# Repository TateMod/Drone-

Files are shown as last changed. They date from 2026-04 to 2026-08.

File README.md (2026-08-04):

drone pcb and c++ develpmnet in progress (MK2) see branch for updates

An open-source sub-250g quadcopter UAV built on custom MicroPython firmware developed from first principles. The platform provides full access to flight control algorithms including PID attitude control, complementary filter sensor fusion, motor mixing, optical flow position hold and TOF altitude hold. Designed to be reproducible and accessible for learning and further development.
this project originated as a dissertation project and where i gave weekly updates to my unis robotics club explaining my work

NOTE: testing with higher I term on all axis test rig to counteract persistence drift and imbalances
---

## pictures




## Demo Videos

| Description | Link |
|---|---|
| Direction control verification | [Watch](https://youtube.com/shorts/0nLSP_-wE7E) |
| Flight with large drop | [Watch](https://youtube.com/shorts/2Yogxh4Vv3w) |
| 1 min tethered flight | [Watch](https://youtube.com/shorts/OXTsZ9uvmPU) |
| Rig test | [Watch](https://youtube.com/shorts/fh2ME875rF4) |
| PID test | [Watch](https://youtube.com/shorts/FNgBR3Ud5JU) |
| Wobbly PID test | [Watch](https://youtube.com/shorts/QxyQJRjCvH8) |

---

## Repository Structure

```
/firmware          - Pico W2 flight controller MicroPython source code
/companion         - Raspberry Pi Zero W2 telemetry and camera code
/schematics        - Wiring diagrams and circuit schematics (EasyEDA)
/frame             - 3D printable CAD frame files (STL and OnShape)
/docs              - Build guide and assembly documentation
```

---

## Components

### Computing
| Component | Purpose |
|---|---|
| Raspberry Pi Pico W2 | Flight controller - runs all flight algorithms |
| Raspberry Pi Zero W2 | Companion computer - telemetry logging and camera |

### Sensors
| Component | Purpose |
|---|---|
| Adafruit LSM9DS1 9-axis IMU | Attitude estimation (roll, pitch, yaw) |
| Adafruit VL53L1X Time of Flight | Altitude estimation |
| PMW3901 Optical Flow Sensor | Position hold assistance |

### Propulsion
| Component | Purpose |
|---|---|
| Flash 1404 4500KV motors (x4) | Generates adequate thrust for ~200g system |
| 3.5 inch tri-blade propellers (x4) | Tri-blade for stable efficient flight at lower speeds |
| HAKRC 45A 4-in-1 BLHeli_S ESC | Controls motor speed via PWM signals |

### Radio
| Component | Purpose |
|---|---|
| FlySky FS-i6X 10CH Transmitter & FS-X6B iBUS Receiver | Receives control commands via iBus |

### Power
| Component | Purpose |
|---|---|
| GNB 1100mAh 2S 60C LiHV LiPo battery | Powers the system |
| Pololu 5V 3A step-up/step-down voltage regulator | Regulates battery voltage to 5V for processors |
| XT30 connectors | Battery and ESC power connections |
| VIFLY Toothstor 4-Port 2S LiPo Charger | Charges the LiPo battery |

### Camera
| Component | Purpose |
|---|---|
| Raspberry Pi Camera Module 3 | Camera feed via companion computer |
| 15-pin to 15-pin adapter | Connects camera to Zero W2 |
| 22-pin to 15-pin ribbon cable | Required for Zero W2 camera connection |

### Tools and Equipment Required
- 60W soldering iron
- Multimeter
- Solder
- Jumper wires
- Zip ties
- Electrical tape
- Allen keys
- Wire clippers
- AA batteries (for transmitter)
- MicroSD card and USB adapter

## Bill of Materials

| Component | Price | Link |
|---|---|---|
| Raspberry Pi Pico W2 | £6.70 | [Buy](https://thepihut.com/products/raspberry-pi-pico-2-w) |
| Raspberry Pi Zero W2 | £14.40 | [Buy](https://thepihut.com/products/raspberry-pi-zero-2) |
| Adafruit LSM9DS1 IMU | £21.60 | [Buy](https://thepihut.com/products/adafruit-9-dof-accel-mag-gyro-temp-breakout-board-lsm9ds1) |
| Adafruit VL53L1X TOF | £14.40 | [Buy](https://thepihut.com/products/adafruit-vl53l1x-time-of-flight-distance-sensor-30-to-4000mm-stemma-qt-qwiic) |
| PMW3901 Optical Flow Sensor | £20.70 | [Buy](https://thepihut.com/products/pmw3901-optical-flow-sensor-breakout) |
| Flash 1404 4500KV motors (x4) | £13.29 each (×4 = £53.16) | [Buy](https://www.unmannedtechshop.co.uk/products/flyfish-flash-1404-4500kv-fpv-motor) |
| 3.5 inch tri-blade propellers | £2.20 | [Buy](https://yourfpv.co.uk/product/hqprop-t3-5x2-5x3-orange-1-5mm-2cw2ccw-copy/) |
| HAKRC 45A 4-in-1 BLHeli_S ESC | £38.95 | [Buy](https://yourfpv.co.uk/product/hakrc-8-bit-45a-twin-mount-30-530-5mm-and-2020mm-4in1-esc/) |
| GNB 1100mAh 2S 60C LiHV LiPo battery | £8.80 | [Buy](https://www.hobbyrc.co.uk/gnb-1100mah-2s-60c-lihv-battery-xt30) |
| Pololu 5V 3A voltage regulator | £17.30 | [Buy](https://thepihut.com/products/pololu-5v-3a-step-up-step-down-voltage-regulator-s13v30f5) |
| XT30 connectors | £5.99 | [Buy](https://www.amazon.co.uk/RUNCCI-Upgrade-Female-Connectors-Battery/dp/B07PC1YKVW) |
| Raspberry Pi Camera Module 3 | £24.00 | [Buy](https://www.raspberrypi.com/products/camera-module-3/) |
| FlySky FS-i6X Transmitter & FS-X6B Receiver | £68.00 | [Buy](https://www.flyingtech.co.uk/product/flysky-fs-i6x-10ch-transmitter-fs-x6b-2-4ghz-ibus-receiver/) |
| VIFLY Toothstor 4-Port 2S LiPo Charger | £25.15 | [Buy](https://www.hobbyrc.co.uk/vifly-toothstor-4-port-2s-lipo-battery-charger) |
| 15-pin to 15-pin camera adapter | £3.00 | [Buy](https://thepihut.com/products/raspberry-pi-zero-camera-adapter) |
| 22-pin to 15-pin ribbon cable | £1.70 | [Buy](https://thepihut.com/products/zero-camera-cable-joiner-for-raspberry-pi-22-pin-to-22-pin) |
| Jumper wires | £5.49 | [Buy](https://www.amazon.co.uk/Multicolored-Dupont-Breadboard-Compatible-Arduino/dp/B0DSZ7FD2V) |
| **Total** | **~£331.54** | |

---

## Wiring

Wiring Diagram
Follow the diagram above for visual guidance on all connections.

### Interface Pin Assignments

| Interface | Protocol | Pins | Purpose |
|---|---|---|---|
| IMU (LSM9DS1) | I2C | SDA: GPIO 4, SCL: GPIO 5 | Attitude data |
| TOF (VL53L1X) | I2C | SDA: GPIO 4, SCL: GPIO 5 | Altitude data |
| Optical Flow (PMW3901) | SPI | MISO: GPIO 16, MOSI: GPIO 19, SCK: GPIO 18, CS: GPIO 17 | Position hold |
| RC Receiver (FS-iA6B) | UART | RX: GPIO 1 | Pilot inputs |
| Motor 1 (Front Left) | PWM | GPIO 11 | Motor speed |
| Motor 2 (Back Left) | PWM | GPIO 14 | Motor speed |
| Motor 3 (Back Right) | PWM | GPIO 12 | Motor speed |
| Motor 4 (Front Right) | PWM | GPIO 13 | Motor speed |
| Calibration Button | GPIO | GPIO 20 (GND on other pin) | Arm and calibrate |

---

## Assembly Guide

### 1. Power System

1. Heat soldering iron to operating temperature
2. Pre-tin the XT30 connector pads
3. Solder 12–14 AWG wires to the XT30 connector - red to positive (+), black to negative (−)
4. Add the capacitor to the ESC capacitor pads, leaving room for the main power wires
5. Solder the XT30 wires to the ESC positive and negative pads, ensuring secure connections
6. Plug in the battery and listen for the ESC power-up beep sequence to confirm correct wiring

### 2. Voltage Regulator

1. Solder ESC VOUT to the regulator VIN
2. Solder ESC GND to the regulator GND
3. The regulator 5V output will supply the Pico W2, Zero W2 and RC receiver

### 3. Motors

1. Cut motor wires to length from motor platform to ESC if required
2. Solder motors to ESC motor pads:
   - Front left and back right motors: clockwise configuration
   - Front right and back left motors: counter-clockwise configuration (swap any two motor wires to reverse direction)

### 4. ESC Signal Wires

1. Using the dual-sided connector supplied with the ESC, snip one end leaving bare wires
2. Solder wires to extend their length to reach the Pico W2 GPIO pins
3. Connect each wire to the corresponding GPIO pin listed in the pin assignments table above

### 5. Sensor Wiring (Without Pico Headers)

**I2C Bus (IMU and TOF - shared bus):**
- Join IMU SCL and TOF SCL together and solder to GPIO 5
- Join IMU SDA and TOF SDA together and solder to GPIO 4

**SPI (Optical Flow):**
- MISO -> GPIO 16
- MOSI -> GPIO 19
- SCK -> GPIO 18
- CS -> GPIO 17

**Sensor Power (3.3V and GND):**
- Run a red wire to the furthest sensor, cutting the wire casing at each intermediate sensor to branch a connection to 3.3V or VIN
- Repeat with a black wire for GND, branching to each sensor

**RC Receiver:**
- Snip a male jumper wire and solder to Pico W2 UART RX GPIO 1
- Connect the other end to the iBus slot on the receiver using the connector supplied with it

### 6. Power Rails for Processors

1. Create a 5V rail by soldering jumper wires directly to the Pico W2 VSYS and Zero W2 5V power pins
2. Solder a male header onto this 5V rail for the RC receiver
3. Create a GND rail by soldering jumper wires to the Pico W2 GND and Zero W2 GND pins
4. Solder a male header onto this GND rail for the RC receiver

### 7. Calibration Button

1. Solder two wires to the button
2. Connect one wire to GPIO 20 and the other to GND

### 8. With Pico Headers (Alternative)

- Solder female headers to the ends of  wires connected to the Pico W2 and Zero W2
- For shared I2C bus wires, solder sensor wires together first and then add a single female header
- Ensure sufficient wire length to allow connections without strain

---

## Firmware Setup

### Pico W2 — Flight Controller

1. Hold the BOOTSEL button on the Pico W2 and connect via USB to enter bootloader mode
2. Download MicroPython V1.27.0 UF2 from the official Raspberry Pi website
3. Drag the UF2 file onto the Pico W2 drive that appears
4. Open Thonny IDE (version 4.1.7 or later)
5. Open the firmware files from the `/firmware` folder
6. Upload all files to the Pico W2 using Thonny
7. Run `main.py` — the drone will wait for the calibration button to be pressed before arming

### Zero W2 — Companion Computer

1. Insert a MicroSD card into your computer using a USB adapter
2. Open Raspberry Pi Imager
3. Select Raspberry Pi Zero 2 W as the device and Raspberry Pi OS Lite as the OS
4. Flash the SD card and insert into the Zero W2
5. Upload the companion computer files from the `/companion` folder

---

## PID Tuning Values

These are the final values used in testing. Adjust based on your build weight and component placement.

| Axis | P | I | D |
|---|---|---|---|
| Roll | 1 | 0.002 | 0.1 |
| Pitch | 1.2 | 0.002 | 0.1 |
| Yaw | 0.5 | 0.0 | 0.0 |
| Altitude | 0.2 | 0.0 | 0.01 |

---

## License

This project is published under the MIT License. All third-party libraries used in the firmware are distributed under permissive open-source licences (MIT and BSD) which permit use, modification and redistribution with attribution.

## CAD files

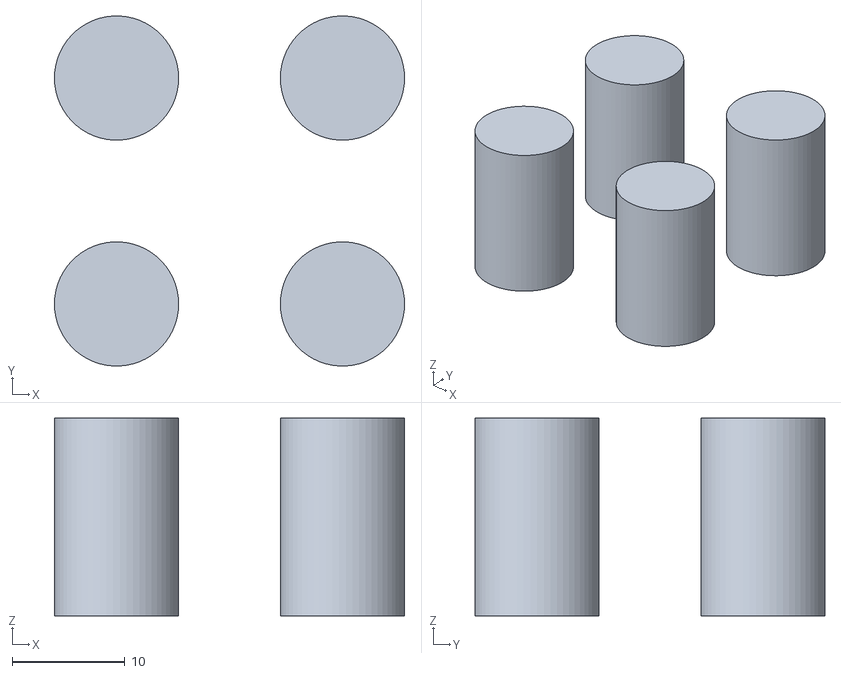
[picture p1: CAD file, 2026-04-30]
legs PT3.stl
31.0 x 31.0 x 17.5

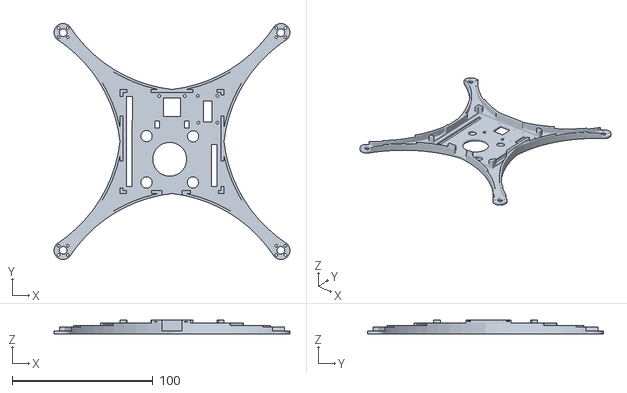
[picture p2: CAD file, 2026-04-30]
drone base PT1.stl
167.9 x 167.9 x 10.0

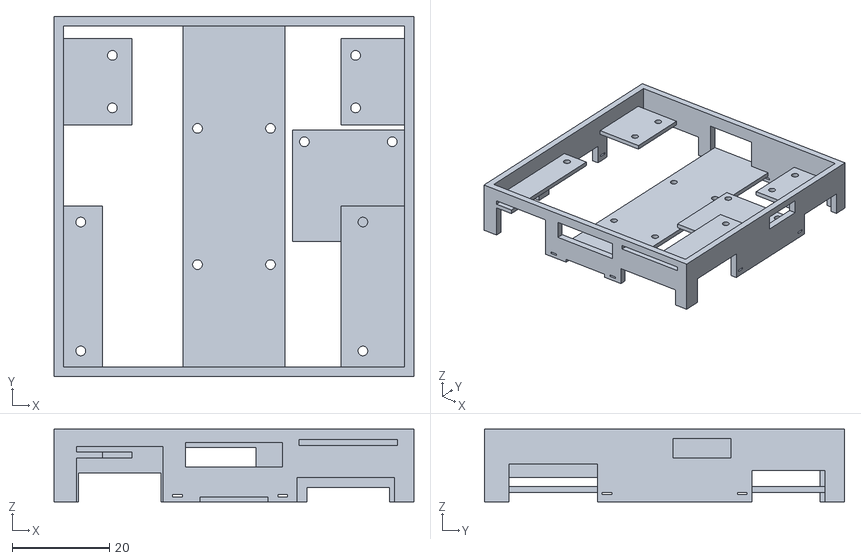
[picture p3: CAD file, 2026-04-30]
drone case PT 2.stl
74.0 x 74.0 x 15.0

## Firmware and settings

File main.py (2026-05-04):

import machine
from machine import UART, Pin
import time
import lsm9ds1
import math
import struct
import VL53L1X
import network
import socket

# PMW3901 optical flow sensor register addresses
REG_ID = 0x00
REG_DATA_READY = 0x02
REG_MOTION_BURST = 0x16          # burst read register for motion data
REG_POWER_UP_RESET = 0x3a        # reset register written on startup
REG_ORIENTATION = 0x5b
WAIT = -1                         # sentinel value used in bulk write sequences to trigger a delay
REG_RAWDATA_GRAB = 0x58
REG_RAWDATA_GRAB_STATUS = 0x59

# WiFi access point broadcasting its own network for telemetry
ap = network.WLAN(network.AP_IF)
ap.config(essid='Pico-Drone', password='password123')
ap.active(True)
print("AP active:", ap.ifconfig()[0])

# UDP broadcast socket with telemetry sent to all devices on the network
sock = socket.socket(socket.AF_INET, socket.SOCK_DGRAM)
sock.setsockopt(socket.SOL_SOCKET, socket.SO_BROADCAST, 1)
target_ip = '192.168.4.255'
target_port = 5005

# Physical button on GPIO20 used to trigger gyroscope calibration on startup
calibrate_button = machine.Pin(20, machine.Pin.IN, machine.Pin.PULL_UP)


class positionHold():
    def __init__(self, flow_sensor, pid_roll, pid_pitch):
        self.sensor = flow_sensor
        self.flowRollPID = pid_roll
        self.flowPitchPID = pid_pitch
        self.GYRO_TO_FLOW_SCALER = 1.2   # tuned scaling factor to match gyro units to optical flow pixel units
        self.MAX_ANGLE = 15.0             # maximum correction angle in degrees to prevent excessive tilt from position hold
        self.last_dx = 0
        self.last_dy = 0

    def process(self, gyro_x, gyro_y):
        raw_dx, raw_dy = self.sensor.get_motion()
        # subtract gyroscope rotation contribution from raw flow reading
        # prevents tilting to correct sensor from reporting false horizontal movement
        compensated_dx = raw_dx - (gyro_x * self.GYRO_TO_FLOW_SCALER)
        compensated_dy = raw_dy - (gyro_y * self.GYRO_TO_FLOW_SCALER)
        # outer PID loop targets zero movement any detected movement produces a corrective angle
        target_roll = self.flowRollPID.computePID(0.0, compensated_dx)
        target_pitch = self.flowPitchPID.computePID(0.0, compensated_dy)
        # clamp correction to prevent position hold commanding excessive tilt
        target_roll = max(-self.MAX_ANGLE, min(self.MAX_ANGLE, target_roll))
        target_pitch = max(-self.MAX_ANGLE, min(self.MAX_ANGLE, target_pitch))
        self.last_dx = compensated_dx
        self.last_dy = compensated_dy
        # returned as target angles fed into the inner attitude PID loop
        return target_roll, target_pitch


class opticalFlow():
    def __init__(self):
        # SPI0 at 400kHz - PMW3901 maximum supported rate
        self.spi = machine.SPI(0, baudrate=400000, polarity=0, phase=0,
                               sck=machine.Pin(18), mosi=machine.Pin(19), miso=machine.Pin(16))
        self.cs = machine.Pin(17, machine.Pin.OUT)
        time.sleep(0.05)                          # allow sensor to power up before communication
        self._write(REG_POWER_UP_RESET, 0x5a)     # trigger hardware reset
        time.sleep(0.02)
        for offset in range(5):                   # clear motion registers after reset
            self._read(REG_DATA_READY + offset)
        self._secret_sauce()                      # manufacturer specified initialisation sequence

    def _bulk_write(self, data):
        # writes pairs of [register, value] from a flat list
        # WAIT sentinel triggers a delay in milliseconds instead of a write
        for x in range(0, len(data), 2):
            register, value = data[x:x + 2]
            if register == WAIT:
                time.sleep(value / 1000)
            else:
                self._write(register, value)

    def _secret_sauce(self):
        # manufacturer specified register initialisation sequence from PMW3901 datasheet
        # required for correct sensor operation - DO NOT MODIFY VALUES
        self._bulk_write([
            0x7f, 0x00, 0x55, 0x01, 0x50, 0x07,
            0x7f, 0x0e, 0x43, 0x10
        ])
        # select performance register value based on sensor variant
        if self._read(0x67) & 0b10000000:
            self._write(0x48, 0x04)
        else:
            self._write(0x48, 0x02)
        self._bulk_write([
            0x7f, 0x00, 0x51, 0x7b,
            0x50, 0x00, 0x55, 0x00, 0x7f, 0x0E
        ])
        if self._read(0x73) == 0x00:
            # read calibration values from sensor and apply mathematical adjustment
            c1 = self._read(0x70)
            c2 = self._read(0x71)
            if c1 <= 28:
                c1 += 14
            if c1 > 28:
                c1 += 11
            c1 = max(0, min(0x3F, c1))   # clamp to valid register range
            c2 = (c2 * 45) // 100
            self._bulk_write([
                0x7f, 0x00, 0x61, 0xad,
                0x51, 0x70, 0x7f, 0x0e
            ])
            self._write(0x70, c1)
            self._write(0x71, c2)
        self._bulk_write([
            0x7f, 0x00, 0x61, 0xad, 0x7f, 0x03, 0x40, 0x00, 0x7f, 0x05,
            0x41, 0xb3, 0x43, 0xf1, 0x45, 0x14, 0x5b, 0x32, 0x5f, 0x34,
            0x7b, 0x08, 0x7f, 0x06, 0x44, 0x1b, 0x40, 0xbf, 0x4e, 0x3f,
            0x7f, 0x08, 0x65, 0x20, 0x6a, 0x18, 0x7f, 0x09, 0x4f, 0xaf,
            0x5f, 0x40, 0x48, 0x80, 0x49, 0x80, 0x57, 0x77, 0x60, 0x78,
            0x61, 0x78, 0x62, 0x08, 0x63, 0x50, 0x7f, 0x0a, 0x45, 0x60,
            0x7f, 0x00, 0x4d, 0x11, 0x55, 0x80, 0x74, 0x21, 0x75, 0x1f,
            0x4a, 0x78, 0x4b, 0x78, 0x44, 0x08, 0x45, 0x50, 0x64, 0xff,
            0x65, 0x1f, 0x7f, 0x14, 0x65, 0x67, 0x66, 0x08, 0x63, 0x70,
            0x7f, 0x15, 0x48, 0x48, 0x7f, 0x07, 0x41, 0x0d, 0x43, 0x14,
            0x4b, 0x0e, 0x45, 0x0f, 0x44, 0x42, 0x4c, 0x80, 0x7f, 0x10,
            0x5b, 0x02, 0x7f, 0x07, 0x40, 0x41, 0x70, 0x00,
            WAIT, 0x0A,
            0x32, 0x44, 0x7f, 0x07, 0x40, 0x40, 0x7f, 0x06, 0x62, 0xf0,
            0x63, 0x00, 0x7f, 0x0d, 0x48, 0xc0, 0x6f, 0xd5, 0x7f, 0x00,
            0x5b, 0xa0, 0x4e, 0xa8, 0x5a, 0x50, 0x40, 0x80,
            WAIT, 0xF0,
            0x7f, 0x14, 0x6f, 0x1c, 0x7f, 0x00
        ])

    def _write(self, register, value):
        self.cs.value(0)
        self.spi.write(bytes([register | 0x80, value]))  # MSB set indicates write operation
        self.cs.value(1)

    def _read(self, register, length=1):
        result = []
        buffer = bytearray(2)
        for x in range(length):
            self.cs.value(0)
            self.spi.write_readinto(bytes([register + x, 0]), buffer)  # send register address and read response
            self.cs.value(1)
            result.append(buffer[1])
        if length == 1:
            return result[0]
        else:
            return result

    def get_motion(self, timeout=0.002):
        in_buffer = bytearray(13)
        out_buffer = bytearray(13)
        out_buffer[0] = REG_MOTION_BURST
        t_start = time.ticks_ms()
        while time.ticks_diff(time.ticks_ms(), t_start) < timeout * 1000:
            self.cs.value(0)
            self.spi.write_readinto(out_buffer, in_buffer)  # burst read all motion data in single SPI transaction
            self.cs.value(1)
            (_, dr, obs, x, y, quality, raw_sum, raw_max, raw_min,
             shutter_upper, shutter_lower) = struct.unpack("<BBBhhBBBBBB", in_buffer)
            # validate data ready flag and reject low quality readings (quality < 25 with maxed shutter)
            if dr & 0b10000000 and not (quality < 0x19 and shutter_upper == 0x1f):
                return x, y
        return 0, 0  # return zero movement if no valid data within timeout


class tof():
    def __init__(self):
        # I2C0 shared with IMU at 400kHz fast mode
        self.i2c = machine.I2C(0, scl=machine.Pin(5), sda=machine.Pin(4), freq=400000)
        self.sensor = VL53L1X.VL53L1X(self.i2c, 0x29)  # default I2C address 0x29
        self.hight = 0

    def readDistance(self):
        raw = self.sensor.read()
        self.hight = 0.9 * self.hight + 0.1 * raw  # first order low pass filter alpha=0.1 smooths sensor noise


class imu():
    def __init__(self):
        # I2C0 shared with TOF sensor
        self.i2c = machine.I2C(0, scl=machine.Pin(5), sda=machine.Pin(4), freq=400000)
        self.sensor = lsm9ds1.LSM9DS1(self.i2c)
        # hard iron offset corrections determined during magnetometer calibration
        self.mag_offset_x = 0.16002001
        self.mag_offset_y = 0.04101999
        self.mag_offset_z = -0.36232
        
        self.Mheading = 0
        self.accel_logic = 0.732
        self.gyro_logic = 70
        self.mag_logic = 0.29
        
        self.start_time = time.ticks_ms()
        self.gyroRollAngle = 0
        self.gyroPitchAngle = 0
        self.gyroYawAngle = 0
        self.gyroXbias = 0.0   # gyroscope bias offsets calculated during calibration routine
        self.gyroYbias = 0.0
        self.gyroZbias = 0.0
        
        self.alpha = 0.98      # complementary filter trust coefficient - 98% gyroscope, 2% accelerometer
        
        self.finalRoll = 0
        self.finalPitch = 0
        self.finalYaw = 0
        self.calibRoll  = 0.0  # initial roll angle captured during calibration to account for IMU mounting offset
        self.calibPitch = 0.0

        print(self.i2c.scan())
        print("Press button to calibrate...")
        while calibrate_button.value() == 1:  # wait for button press before calibrating
            pass
        print("Button pressed! Place drone still...")
        time.sleep(3)
        self.calibrateGyro()

    def calibrateGyro(self, samples=200):
        # samples gyroscope and accelerometer at rest to calculate bias offsets
        # drone must remain still during 
        print("Keep drone still... calibrating gyro")
        time.sleep(2)
        bx, by, bz = 0, 0, 0
        roll_sum, pitch_sum = 0, 0
        for _ in range(samples):
            g = self.sensor.read_gyro()
            a = self.sensor.read_accel()
            bx += -g[1]
            by += g[0]
            bz += g[2]
            # remap accelerometer axes to match physical sensor orientation on frame
            Xa = a[1]
            Ya = -a[0]
            Za = a[2]
            roll_sum  += math.atan2(Ya, Za) * (180 / math.pi)
            pitch_sum += math.atan2(-Xa, math.sqrt(Ya**2 + Za**2)) * (180 / math.pi)
            time.sleep(0.01)
        self.gyroXbias = bx / samples  # average bias across all samples
        self.gyroYbias = by / samples
        self.gyroZbias = bz / samples
        self.gyroRollAngle  = roll_sum  / samples
        self.gyroPitchAngle = pitch_sum / samples
        self.calibRoll  = self.gyroRollAngle   # store initial angle to compensate for IMU mounting offset
        self.calibPitch = self.gyroPitchAngle
        print(f"Bias X:{self.gyroXbias:.3f} Y:{self.gyroYbias:.3f} Z:{self.gyroZbias:.3f}")
        print(f"Starting angle Roll:{self.gyroRollAngle:.1f} Pitch:{self.gyroPitchAngle:.1f}")
        self.start_time = time.ticks_ms()

    def readIMU(self):
        self.accel = self.sensor.read_accel()
        self.gyro = self.sensor.read_gyro()
        #self.mag = self.sensor.read_mag()

    def readMag(self):
        # subtract hard iron offsets from raw magnetometer readings
        self.Xm = self.mag[0] - self.mag_offset_x
        self.Ym = self.mag[1] - self.mag_offset_y
        self.Zm = self.mag[2] - self.mag_offset_z

    def magCal(self):
        self.XMcal = self.Xm
        self.YMcal = self.Ym
        self.ZMcal = self.Zm

    def magposition(self):
        # tilt compensate magnetometer using filtered roll and pitch angles
        # projects magnetometer axes onto horizontal plane for accurate heading
        roll_rad = math.radians(self.finalRoll)
        pitch_rad = math.radians(self.finalPitch)
        Xh = self.XMcal * math.cos(pitch_rad) + self.ZMcal * math.sin(pitch_rad)
        Yh = self.XMcal * math.sin(roll_rad) * math.sin(pitch_rad) + self.YMcal * math.cos(roll_rad) - self.ZMcal * math.sin(roll_rad) * math.cos(pitch_rad)
        Mposition = math.atan2(Yh, Xh)
        self.Mheading = Mposition * (180 / math.pi)
        if self.Mheading < 0:
            self.Mheading += 360  # convert to 0-360 range

    def readAccell(self):
        # remap accelerometer axes to match physical sensor orientation on frame
        self.Xa = self.accel[1]
        self.Ya = -self.accel[0]
        self.Za = self.accel[2]

    def accellCal(self):
        self.XAcal = self.Xa
        self.YAcal = self.Ya
        self.ZAcal = self.Za

    def accellAngles(self):
        # calculate roll and pitch from gravity vector using atan2
        Aroll = math.atan2(self.YAcal, self.ZAcal)
        self.ARdegrees = Aroll * (180 / math.pi)   # convert radians to degrees
        Apitch = math.atan2(-self.XAcal, math.sqrt(self.YAcal**2 + self.ZAcal**2))
        self.APdegrees = Apitch * (180 / math.pi)

    def readGyro(self):
        # remap gyroscope axes to match physical sensor orientation on frame
        self.Xg = -self.gyro[1]
        self.Yg = self.gyro[0]
        self.Zg = self.gyro[2]

    def gyroCal(self):
        # subtract calibration bias from raw gyroscope readings
        self.XGcal = (self.Xg - self.gyroXbias)
        self.YGcal = (self.Yg - self.gyroYbias)
        self.ZGcal = (self.Zg - self.gyroZbias)

    def gyroAngle(self):
        # numerical integration of gyroscope rate to accumulate angle
        dt = time.ticks_diff(time.ticks_ms(), self.start_time) / 1000
        self.start_time = time.ticks_ms()
        self.gyroRollAngle  += self.XGcal * dt
        self.gyroPitchAngle += self.YGcal * dt
        self.gyroYawAngle   += self.ZGcal * dt

    def complimentoryFilter(self):
        # complementary filter fuses gyroscope and accelerometer estimates
        # alpha=0.98 trusts gyroscope for short term accuracy
        # (1-alpha)=0.02 corrects with accelerometer to prevent long term drift
        self.finalRoll  = (self.alpha * self.gyroRollAngle)  + ((1 - self.alpha) * self.ARdegrees)
        self.finalPitch = (self.alpha * self.gyroPitchAngle) + ((1 - self.alpha) * self.APdegrees)
        self.gyroRollAngle  = self.finalRoll   # reset gyro angle to filter output each loop to prevent drift accumulation
        self.gyroPitchAngle = self.finalPitch

    def updateYaw(self):
        # fuse gyroscope yaw rate with magnetometer heading using complementary filter
        self.finalYaw = self.alpha * self.gyroYawAngle + (1 - self.alpha) * self.Mheading


class BiquadFilter:
    def __init__(self, cutoff_hz, sample_hz):
        # second order Butterworth low pass filter coefficients
        # used on gyroscope D term input to attenuate high frequency noise above cutoff
        w = 2 * math.pi * cutoff_hz / sample_hz
        q = 0.707          # Butterworth maximally flat response
        k = math.tan(w / 2)
        norm = 1 / (1 + k / q + k * k)
        self.b0 = k * k * norm
        self.b1 = 2 * self.b0
        self.b2 = self.b0
        self.a1 = 2 * (k * k - 1) * norm
        self.a2 = (1 - k / q + k * k) * norm
        self.x1 = self.x2 = 0.0  # input history
        self.y1 = self.y2 = 0.0  # output history

    def update(self, x):
        # direct form II transposed biquad implementation
        y = self.b0*x + self.b1*self.x1 + self.b2*self.x2 - self.a1*self.y1 - self.a2*self.y2
        self.x2, self.x1 = self.x1, x
        self.y2, self.y1 = self.y1, y
        return y

    def reset(self):
        self.x1 = self.x2 = 0.0
        self.y1 = self.y2 = 0.0


class PID():
    def __init__(self, kp, ki, kd):
        self.kp = kp
        self.ki = ki
        self.kd = kd
        self.accumulated_error = 0
        self.last_error = 0
        self.start_time = time.ticks_ms()
        self.d_filter = BiquadFilter(cutoff_hz=20, sample_hz=100)  # biquad filter on D term - 20Hz cutoff at 100Hz sample rate

    def computePID(self, target, current_value, gyro_rate=None):
        dt = time.ticks_diff(time.ticks_ms(), self.start_time) / 1000
        self.start_time = time.ticks_ms()
        if dt <= 0 or dt > 0.5:  # reject invalid dt to prevents large corrections after timing gaps or first call
            return 0.0

        error = target - current_value
        p_term = self.kp * error  # proportional: responds to current error magnitude

        self.accumulated_error += error * dt
        self.accumulated_error = max(-50, min(50, self.accumulated_error))  # clamp to +-50 to prevent integral windup oscillation
        i_term = self.ki * self.accumulated_error  # integral: eliminates steady state offset over time

        if gyro_rate is not None:
            d_term = -self.kd * self.d_filter.update(gyro_rate)  # derivative from filtered gyro rate - more accurate than error difference
        else:
            error_change = (error - self.last_error) / dt if dt > 0 else 0.0
            d_term = self.kd * error_change  # fallback derivative from error change if no gyro rate supplied

        self.last_error = error
        return p_term + i_term + d_term

    def reset(self):
        # reset all state on disarm to prevent accumulated error affecting next flight
        self.accumulated_error = 0
        self.last_error = 0
        self.d_filter.reset()
        self.start_time = time.ticks_ms()


class remote():
    def __init__(self):
        # UART0 at 115200 baud - iBus protocol from FS-iA6B receiver
        self.uart = UART(0, baudrate=115200, rx=Pin(1))
        self.channels = []
        # initialise channels to safe defaults - centred sticks, minimum throttle
        self.roll = 1500
        self.pitch = 1500
        self.throttle = 1000
        self.yaw = 1500
        self.arming = 0

    def DataParse(self):
        self.data = self.uart.read(32)  # iBus frame is 32 bytes
        if self.data is None:
            return
        if self.data[0] == 0x20 and self.data[1] == 0x40:  # validate iBus header bytes
            self.channels = []
            for i in range(2, len(self.data) - 2, 2):  # skip first 2 header and last 2 checksum bytes
                self.value = (self.data[i + 1] * 256) + self.data[i]  # reconstruct 16-bit value from two bytes little-endian
                self.channels.append(self.value)
            if len(self.channels) >= 4:
                self.roll = self.channels[0]
                self.pitch = self.channels[1]
                self.yaw = self.channels[3]
                if 1000 <= self.channels[2] <= 2000:
                    self.throttle = self.channels[2]
                # clamp channels to valid range - reject corrupt packet values
                if not (1000 <= self.roll  <= 2000): self.roll  = 1500
                if not (1000 <= self.pitch <= 2000): self.pitch = 1500
                if not (1000 <= self.yaw   <= 2000): self.yaw   = 1500
            if len(self.channels) >= 5:
                self.arming = self.channels[4]  # channel 5 used as arming switch


class motor():
    def __init__(self):
        # PWM at 400Hz - BLHeli_S ESC supports higher rates than standard 50Hz for faster correction response
        self.moterPin1 = machine.Pin(11)  # FL - front left
        self.PWMmoterPin1 = machine.PWM(self.moterPin1)
        self.PWMmoterPin1.freq(400)
        self.PWMmoterPin1.duty_u16(3277)  # initialise to minimum throttle (1ms pulse width)

        self.moterPin2 = machine.Pin(14)  # BL - back left
        self.PWMmoterPin2 = machine.PWM(self.moterPin2)
        self.PWMmoterPin2.freq(400)
        self.PWMmoterPin2.duty_u16(3277)

        self.moterPin3 = machine.Pin(12)  # BR - back right
        self.PWMmoterPin3 = machine.PWM(self.moterPin3)
        self.PWMmoterPin3.freq(400)
        self.PWMmoterPin3.duty_u16(3277)

        self.moterPin4 = machine.Pin(13)  # FR - front right
        self.PWMmoterPin4 = machine.PWM(self.moterPin4)
        self.PWMmoterPin4.freq(400)
        self.PWMmoterPin4.duty_u16(3277)

        self.motorPitch = 0
        self.motorRoll = 0
        self.motorThrottle = 0
        self.motorYaw = 0
        self.motor1_pwm = 0
        self.motor2_pwm = 0
        self.motor3_pwm = 0
        self.motor4_pwm = 0

    def motorProcessing(self, throttle, roll_correction, pitch_correction, yaw_correction):
        self.motorPitch = pitch_correction
        self.motorRoll = roll_correction
        self.motorThrottle = throttle
        self.motorYaw = yaw_correction

    def motorMixing(self):
        # X configuration motor mixing matrix
        # each motor receives throttle base plus signed corrections for each axis
        self.motor1_pwm = self.motorThrottle + self.motorRoll + self.motorPitch + self.motorYaw  # FL: +roll +pitch +yaw
        self.motor2_pwm = self.motorThrottle + self.motorRoll - self.motorPitch - self.motorYaw  # BL: +roll -pitch -yaw
        self.motor3_pwm = self.motorThrottle - self.motorRoll - self.motorPitch + self.motorYaw  # BR: -roll -pitch +yaw
        self.motor4_pwm = self.motorThrottle - self.motorRoll + self.motorPitch - self.motorYaw  # FR: -roll +pitch -yaw

        if self.motorThrottle < 1050:
            # safety cutoff - force all motors to minimum when throttle below threshold
            self.PWMmoterPin1.duty_u16(3277)
            self.PWMmoterPin2.duty_u16(3277)
            self.PWMmoterPin3.duty_u16(3277)
            self.PWMmoterPin4.duty_u16(3277)
        else:
            # clamp output to valid ESC range: 3277=1ms minimum, 6554=2ms maximum at 400Hz on 16-bit register
            self.PWMmoterPin1.duty_u16(max(3277, min(6554, pwm.PWMmap(self.motor1_pwm))))
            self.PWMmoterPin2.duty_u16(max(3277, min(6554, pwm.PWMmap(self.motor2_pwm))))
            self.PWMmoterPin3.duty_u16(max(3277, min(6554, pwm.PWMmap(self.motor3_pwm))))
            self.PWMmoterPin4.duty_u16(max(3277, min(6554, pwm.PWMmap(self.motor4_pwm))))
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

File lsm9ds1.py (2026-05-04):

import machine
import struct
import time
from micropython import const

# Registers & Constants
_LSM9DS1_ADDRESS_ACCELGYRO = const(0x6B)
_LSM9DS1_ADDRESS_MAG = const(0x1E)
_LSM9DS1_XG_ID = const(0b01101000)
_LSM9DS1_MAG_ID = const(0b00111101)

# Linear Acceleration: mg per LSB
_LSM9DS1_ACCEL_MG_LSB_2G = 0.061
_LSM9DS1_ACCEL_MG_LSB_4G = 0.122
_LSM9DS1_ACCEL_MG_LSB_8G = 0.244
_LSM9DS1_ACCEL_MG_LSB_16G = 0.732

# Magnetic Field: mgauss per LSB
_LSM9DS1_MAG_MGAUSS_4GAUSS = 0.14
_LSM9DS1_MAG_MGAUSS_8GAUSS = 0.29
_LSM9DS1_MAG_MGAUSS_12GAUSS = 0.43
_LSM9DS1_MAG_MGAUSS_16GAUSS = 0.58

# Gyroscope: dps per LSB
_LSM9DS1_GYRO_DPS_DIGIT_245DPS = 0.00875
_LSM9DS1_GYRO_DPS_DIGIT_500DPS = 0.01750
_LSM9DS1_GYRO_DPS_DIGIT_2000DPS = 0.07000

# Registers
_LSM9DS1_REGISTER_WHO_AM_I_XG = const(0x0F)
_LSM9DS1_REGISTER_CTRL_REG1_G = const(0x10)
_LSM9DS1_REGISTER_CTRL_REG2_G = const(0x11)
_LSM9DS1_REGISTER_CTRL_REG3_G = const(0x12)
_LSM9DS1_REGISTER_CTRL_REG4 = const(0x1E)
_LSM9DS1_REGISTER_CTRL_REG5_XL = const(0x1F)
_LSM9DS1_REGISTER_CTRL_REG6_XL = const(0x20)
_LSM9DS1_REGISTER_CTRL_REG7_XL = const(0x21)
_LSM9DS1_REGISTER_CTRL_REG8 = const(0x22)

_LSM9DS1_REGISTER_OUT_X_L_G = const(0x18)
_LSM9DS1_REGISTER_OUT_X_L_XL = const(0x28)
_LSM9DS1_REGISTER_OUT_X_L_M = const(0x28)

_LSM9DS1_REGISTER_WHO_AM_I_M = const(0x0F)
_LSM9DS1_REGISTER_CTRL_REG1_M = const(0x20)
_LSM9DS1_REGISTER_CTRL_REG2_M = const(0x21)
_LSM9DS1_REGISTER_CTRL_REG3_M = const(0x22)

# User Constants
ACCELRANGE_2G = 0b00 << 3
ACCELRANGE_16G = 0b01 << 3
ACCELRANGE_4G = 0b10 << 3
ACCELRANGE_8G = 0b11 << 3
MAGGAIN_4GAUSS = 0b00 << 5
GYROSCALE_500DPS = 0b00 << 3#was 245

class LSM9DS1:
    def __init__(self, i2c):
        self.i2c = i2c
        # Soft reset & reboot accel/gyro
        self._write_u8(_LSM9DS1_ADDRESS_ACCELGYRO, _LSM9DS1_REGISTER_CTRL_REG8, 0x05)
        # Soft reset & reboot magnetometer
        self._write_u8(_LSM9DS1_ADDRESS_MAG, _LSM9DS1_REGISTER_CTRL_REG2_M, 0x0C)
        time.sleep(0.01)
        # ADD after time.sleep(0.01) in __init__
        self._write_u8(_LSM9DS1_ADDRESS_ACCELGYRO, _LSM9DS1_REGISTER_CTRL_REG8, 0x44)

        # Enable Gyro (Continuous)
        self._write_u8(_LSM9DS1_ADDRESS_ACCELGYRO, _LSM9DS1_REGISTER_CTRL_REG1_G, 0xC0)#was 0xc8
        # Enable Accel (Continuous)
        self._write_u8(_LSM9DS1_ADDRESS_ACCELGYRO, _LSM9DS1_REGISTER_CTRL_REG5_XL, 0x38)
        self._write_u8(_LSM9DS1_ADDRESS_ACCELGYRO, _LSM9DS1_REGISTER_CTRL_REG6_XL, 0xC0)
        # Enable Mag (Continuous)
        self._write_u8(_LSM9DS1_ADDRESS_MAG, _LSM9DS1_REGISTER_CTRL_REG3_M, 0x00)

    def _write_u8(self, address, reg, value):
        self.i2c.writeto_mem(address, reg, bytes([value]))

    def _read_bytes(self, address, reg, count):
        # We add 0x80 to the register address to enable AUTO-INCREMENT
        # This solves the "frozen data" issue you were having!
        return self.i2c.readfrom_mem(address, reg | 0x80, count)

    def read_accel(self):
        # Read 6 bytes starting from OUT_X_L_XL
        data = self._read_bytes(_LSM9DS1_ADDRESS_ACCELGYRO, _LSM9DS1_REGISTER_OUT_X_L_XL, 6)
        raw_x, raw_y, raw_z = struct.unpack_from("<hhh", data)
        # Convert to Gs (assuming default 2G range)
        scale = _LSM9DS1_ACCEL_MG_LSB_2G / 1000.0
        return raw_x * scale, raw_y * scale, raw_z * scale

    def read_gyro(self):
        data = self._read_bytes(_LSM9DS1_ADDRESS_ACCELGYRO, _LSM9DS1_REGISTER_OUT_X_L_G, 6)
        raw_x, raw_y, raw_z = struct.unpack_from("<hhh", data)
        # Convert to DPS (assuming default 500dps)
        scale = _LSM9DS1_GYRO_DPS_DIGIT_245DPS#was500
        return raw_x * scale, raw_y * scale, raw_z * scale

    def read_mag(self):
        data = self._read_bytes(_LSM9DS1_ADDRESS_MAG, _LSM9DS1_REGISTER_OUT_X_L_M, 6)
        raw_x, raw_y, raw_z = struct.unpack_from("<hhh", data)
        # Convert to Gauss (assuming default 4G)
        scale = _LSM9DS1_MAG_MGAUSS_4GAUSS / 1000.0
        return raw_x * scale, raw_y * scale, raw_z * scale

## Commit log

2026-04-30 Revise README for comprehensive project overviewreadmy
    Updated README to provide detailed project information, including demo video, repository structure, components, wiring, assembly guide, firmware setup, PID tuning values, and licensing.
2026-05-03 Update wiring diagram in README
2026-07-26 Update README with current project status
